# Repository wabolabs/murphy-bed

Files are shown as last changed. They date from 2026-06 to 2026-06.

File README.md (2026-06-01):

# Malm Queen → Murphy Bed Conversion

OSB cabinet + direct-bracket VEVOR kit conversion of an IKEA Malm Queen bed frame into a wall-mounted Murphy bed. Cost-optimized design: ~$260–330 in materials.

## Contents

| Path | Description |
|---|---|
| `design/design.html` | Full design doc with SVG diagrams, construction steps, shopping list |
| `design/design.md` | Same content in Markdown |
| `design/diagrams/` | 6 dimensioned SVG diagrams (assembly, panels, mounting, exploded, ceiling, bed-open) |
| `design/3d/` | Programmatic CadQuery 3D model (27-part assembly, STL/STEP, Three.js viewer) |
| `ref/` | Original VEVOR kit manual and IKEA MALM assembly instructions (PDFs) |

## 3D Viewer

```bash
./view.sh          # starts server + opens browser
# or manually:    python3 -m http.server 8080
# then open:      http://localhost:8080/design/3d/viewer.html
```

Opens a Three.js viewer with the full assembly in 3D. Orbit with mouse, switch between Open / Stored / Cabinet Only / Exploded views.

> Opening `design/3d/viewer.html` directly via `file://` will fail due to browser CORS policy. Use `./view.sh` to serve it locally.

## License

MIT — see [LICENSE](LICENSE).

The PDFs in `ref/` are copyright their respective owners (VEVOR/BAGUO and IKEA) and are included for reference only.

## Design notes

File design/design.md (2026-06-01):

# Malm Queen + VEVOR Murphy Bed Kit — Design Document (Cost-Optimized)

> **Project**: Convert an IKEA Malm Queen bed frame into a wall-mounted Murphy (fold-up) bed using a VEVOR/BAGUO Queen Vertical Murphy Bed Kit (YFHVQN246).  
> **Room constraint**: 83.5 in (2121 mm) ceiling with attic/crawl space above for recess.  
> **Date**: 2026-06-01 — **Updated for cost optimization**

---

## Contents

1. [Key Dimensions](#1-key-dimensions)
2. [Design Overview](#2-design-overview)
3. [Figure 1: Overall Assembly](#3-figure-1-overall-assembly)
4. [Figure 2: Cabinet Panel Cutting Guide](#4-figure-2-cabinet-panel-cutting-guide)
5. [Figure 3: Bracket Mounting Detail](#5-figure-3-bracket-mounting-detail)
6. [Figure 4: Exploded View](#6-figure-4-exploded-view)
7. [Figure 5: Ceiling Recess Framing Plan](#7-figure-5-ceiling-recess-framing-plan)
8. [Figure 6: Side View — Bed in Open Position](#8-figure-6-side-view--bed-in-open-position)
9. [Cost Optimization Summary](#9-cost-optimization-summary)
10. [Construction Steps](#10-construction-steps)
11. [Hardware Store Shopping List](#11-hardware-store-shopping-list)
12. [Assembly Sequence](#12-assembly-sequence)
13. [Key Constraints](#13-key-constraints)

---

## 1. Key Dimensions

### Room

| Measurement | US | Metric |
|---|---|---|
| Ceiling height | 83.5 in | 2121 mm |
| Above ceiling | Attic / crawl space | |

### VEVOR Murphy Bed Kit (Queen Vertical — YFHVQN246)

| Component | US | Metric |
|---|---|---|
| Cabinet internal (W × D × H) | 65 1/8 × 15 1/4 × 82 3/4 in | 1654 × 388 × 2102 mm |
| Cabinet external (w/ 3/4 in OSB) | **66.5 × 16 × 84.25 in** | **1690 × 406 × 2138 mm** |
| Kit bed frame (L × W) | 81 3/4 × 64 3/8 in | 2077 × 1634 mm |
| Queen mattress | 60 × 80 in | 1520 × 2030 mm |
| Max mattress weight | 68 lb | 31 kg |
| Total bed weight (frame + mattress) | 202-209 lb | 92-95 kg |

### IKEA Malm Bed Frame (Queen)

| Dimension | US | Metric |
|---|---|---|
| Overall length (with head/footboard) | 83 1/8 in (2111 mm) | |
| Overall width | 66 1/8 in (1680 mm) | |
| **Side rail length** (head/footboard **removed**) | **~79 1/2 in** | **~2020 mm** |
| Mattress platform width | 59 7/8 in | 1521 mm |
| Platform height off floor | 8 1/4 in | 210 mm |

### Ceiling Fit Analysis

| Component | US | Result |
|---|---|---|
| Cabinet external (3/4 in OSB) | **84.25 in (2138 mm)** | Fits with minimal recess |
| Ceiling height | 83.5 in (2121 mm) | |
| **Recess needed** | **0.65 in (17 mm)** | — no header required |
| Malm side rail (stored vertical) | ~79 1/2 in (~2020 mm) | Fits inside cabinet (82 3/4 in) |

---

## 2. Design Overview

**Approach**: Build the Murphy cabinet using **OSB (oriented strand board)** panels for cost savings, and mount the Murphy **Connect Brackets directly to the Malm side rails** — eliminating the plywood adapter strips. The cabinet is only slightly taller than the ceiling, requiring a **~5/8 in (17 mm) recess** — a simple trim-drywall detail rather than a structural framing project.

### Why This Works

1. **OSB is strong enough**: OSB has equivalent shear strength to plywood at the same thickness, and costs ~40% less. For a Murphy bed cabinet (static vertical load, well-braced), OSB is ideal.
2. **Direct mount is simpler**: The Connect Bracket's 11 mm pivot pin carries the full vertical load in shear. Drilling this hole directly into the Malm particleboard side rail is safe — the pin distributes the load, and the M5 screws just prevent rotation.
3. **Minimum ceiling recess**: With 3/4 in OSB panels (18 mm actual), the cabinet external height is 84.25 in. The ceiling is 83.5 in. The 0.65 in gap is easily handled with trim and blocking — no joist cutting or structural header needed.
4. **Lighter = better**: Eliminating the adapter strips (~5.5 lb) and M8 bolts (~1 lb) reduces total bed weight, helping the gas springs lift more easily.
5. **Reversible enough**: The only "permanent" modification is drilling 11 mm holes in the Malm side rails, which are hidden inside the cabinet. The bed can be returned to standalone use by filling the holes.

> **Cost savings summary**: OSB vs. plywood saves ~$75. No adapter strips saves ~$26 in hardware. No structural ceiling header saves ~$15. Total savings: **~$116** vs. the original design.

---

## 3. Figure 1: Overall Assembly

Overall Assembly

*Front elevation (left) and side section (right) showing the OSB cabinet with a 0.65 in ceiling recess.*

---

## 4. Figure 2: Cabinet Panel Cutting Guide

Panel Cutting Guide

*All cabinet panels cut from OSB. The back panel uses 1/2 in OSB for weight savings.*

### Panel Summary

| # | Description | US Dimensions | Metric | Material | Qty |
|---|---|---|---|---|---|
| 1 | Cabinet side | 84 1/4 × 16 in | 2138 × 406 mm | 3/4 in OSB | 2 |
| 2 | Cabinet top | 65 1/8 × 15 1/4 in | 1654 × 388 mm | 3/4 in OSB | 1 |
| 3 | Cabinet bottom | 65 1/8 × 16 in | 1654 × 406 mm | 3/4 in OSB | 1 |
| 4 | Interior shelf | 65 1/8 × 15 1/4 in | 1654 × 388 mm | 3/4 in OSB | 1 |
| 5 | Back panel | 82 3/4 × 66.5 in | 2102 × 1690 mm | 1/2 in OSB | 1 |

### Why OSB?

OSB (oriented strand board) is significantly cheaper than plywood:
- **3/4 in OSB (4×8)**: ~$35/sheet vs. ~$60 for sanded plywood
- **1/2 in OSB (4×8)**: ~$25/sheet vs. ~$55 for sanded plywood
- **Total savings**: ~$90-100 on sheet goods

OSB is strong in shear and compression — ideal for a cabinet box. The surface is rough, but since the cabinet is mostly hidden behind the bed, this isn't a concern. For visible areas, prime with shellac-based primer and paint, or face with 1/4 in plywood skin.

### Mattress Support

Instead of the kit's 3/8 in plywood mattress support panel, re-use the **existing Malm slatted base** (Luroy slats + SKORVA center beam). This is already included with the bed and provides excellent ventilation for the mattress.

---

## 5. Figure 3: Bracket Mounting Detail

Bracket Mounting

*Detail A: Side Bracket (A) mounted to 3/4 in OSB cabinet side. Detail B: Connect Bracket (B) mounted directly to the Malm particleboard side rail.*

### Direct-Mount Specifications

| Property | Value |
|---|---|
| Connect Bracket (B) mounting | Directly to Malm side rail via 11 mm pivot pin |
| Pivot hole in Malm rail | 7/16 in (11 mm) diameter — drill through particleboard |
| Screws for Bracket B | M5×20 mm (#10) — pre-drill pilot holes |
| Side Bracket (A) mounting | To OSB cabinet side with template 28 × 11 5/8 in (710 × 294 mm) |
| Side Bracket pivot hole depth | 5/8 in (15 mm) — leaves ~3 mm in 18 mm OSB |
| No adapter strips needed | Eliminates ~5.5 lb weight and ~$26 in hardware |

### Hole Pattern Transfer

Use the Connect Bracket drilling template (306 × 82 mm / 12 × 3 1/4 in) to mark the pivot pin and screw positions on the Malm side rail. Align the template so the bracket positions the bed at the correct height for the pivot geometry (see Figure 5).

### Particleboard Notes

Particleboard holds screws adequately when pilot holes are pre-drilled. The 11 mm pivot pin carries the vertical/shear load; the M5 screws only prevent the bracket from rotating. For extra grip, dip screws in wood glue before driving.

---

## 6. Figure 4: Exploded View

Exploded View

*All components shown in their relative positions: OSB cabinet panels, mechanism brackets, Malm side rails with slatted base.*

---

## 7. Figure 5: Ceiling Recess Framing Plan

Ceiling Framing

*Top view of ceiling rough opening and section of cabinet-ceiling interface.*

### Rough Opening Dimensions

| Dimension | US | Metric | Calculation |
|---|---|---|---|
| Width | **67.5 in** | **1715 mm** | Cabinet 66.5 in + ~1 in shim gap |
| Depth | **18 in** | **457 mm** | Cabinet 16 in + ~2 in for trim/access |

The recess is only **0.65 in (17 mm)** deep — this is purely a drywall/trim detail:

- Open ceiling drywall to expose joists in the opening area
- Install 2×4 blocking between joists for trim attachment
- No need to cut joists or install a header
- Shim cabinet plumb, fasten through sides into blocking with 3 in deck screws
- Install crown moulding or L-trim to conceal the gap

> **The 0.65 in recess requires no structural ceiling modifications.** This eliminates ~$15 in framing lumber and significant labor vs. the original 3.6 in recess design.

---

## 8. Figure 6: Side View — Bed in Open Position

Bed Open

*Side view of the bed in the horizontal (open) position with pivot geometry and gas spring.*

### Pivot Point Geometry

| Measurement | Value |
|---|---|
| Pivot center (Side Bracket A) | Matches kit template position |
| Leg C center-to-ground | **12 1/4 in (310 mm)** — per kit spec |
| Bed platform height off floor | ~12 1/4 in (Malm is 8 1/4 in — legs raise to match) |

---

## 9. Cost Optimization Summary

### What Changed vs. Original Design

| Item | Original | Optimized | Savings |
|---|---|---|---|
| Cabinet panels | Sanded plywood (3/4 in + 1/2 in) — ~$280 | OSB (3/4 in + 1/2 in) — ~$130 | **~$150** |
| Adapter strips | 2 × 3/4 in plywood strips | Eliminated — direct mount | **~$26** (hardware) |
| Ceiling header | Double 2×6 + cripples + drywall patch | Blocking only + trim | **~$15** |
| Total material cost | ~$420-500 | **~$260-330** | **~$130-170** |
| Weight (adapter + bolts) | ~6.5 lb added | 0 lb added | Bed is lighter |

### What's the Same

- Internal cabinet dimensions (1654 × 388 × 2102 mm)
- Bracket positions and templates
- Gas spring installation
- Malm bed frame with slatted base
- L-bracket hanger strips (3174 mm) for wall/cabinet attachment

### What Changed

- Cabinet panels: 3/4 in OSB instead of 3/4 in + 1 in plywood
- External dimensions: 1690 × 406 × 2138 mm (was 1704 × 438 × 2212 mm) — narrower, shorter
- Ceiling recess: 0.65 in (was 3.6 in)
- Mounting: Connect Bracket direct to Malm (no adapter strips)
- No 3/8 in mattress support panel needed — re-use Malm slats
- Fewer interior shelves: 1 shelf instead of 2

---

## 10. Construction Steps

### Phase 1: Ceiling Preparation

1. Locate ceiling joists with stud finder, mark opening: ~67.5 × 18 in
2. Cut drywall, install 2×4 blocking between joists at opening perimeter
3. Confirm rough opening is square and level

### Phase 2: Cabinet Construction

1. Cut all OSB panels per Figure 2
2. Assemble cabinet box with 3 in deck screws + waterproof wood glue (Titebond III)
3. Verify internal dimensions: **65 1/8 × 15 1/4 × 82 3/4 in**
4. Install interior shelf
5. Prime/paint visible surfaces with shellac-based primer (Zinsser BIN)

### Phase 3: Bracket Installation

1. Mount **Side Brackets (A)** to OSB cabinet interior using template **28 × 11 5/8 in (710 × 294 mm)**
2. Drill 7/16 in (11 mm) pivot hole 5/8 in (15 mm) deep + 1/4 in locator hole
3. Fix brackets with screws I (M5×20 mm) from kit

### Phase 4: Direct Mount Connect Brackets to Malm

1. Remove Malm headboard and footboard
2. Clamp Connect Bracket template **12 × 3 1/4 in (306 × 82 mm)** to each Malm side rail
3. Transfer hole positions (1 pivot + screw holes)
4. Pre-drill pilot holes for screws (3/16 in / 4.5 mm bit)
5. Drill 7/16 in (11 mm) pivot hole through particleboard
6. Mount **Connect Brackets (B)** with screws I — dip screws in wood glue for grip
7. Press **Bearings (F)** into Connect Brackets
8. Attach **Legs (C)** near foot end — 12 1/4 in center-to-ground
9. Install **Gas Springs (D)** — turn end caps out, thread into Connect Brackets, secure with M8 nuts

### Phase 5: Bed Frame Preparation

1. Reattach Malm slatted base (Luroy slats) to side rails
2. Install SKORVA center support beam
3. Slide bed frame assembly into cabinet — Connect Brackets ride on Side Brackets
4. Close and test pivot motion

### Phase 6: Final Assembly

1. Attach **Mattress Straps (E)** with Screws J — centered on mattress location
2. Install **Stoppers (G)** with Screws J
3. Slide cabinet into ceiling opening
4. Shim plumb, fasten through sides into ceiling blocking with 3 in deck screws every 12 in
5. Install crown moulding or L-trim around ceiling perimeter
6. Place mattress (max 10 in thick, max 68 lb) and secure with straps
7. Test open/close cycle multiple times — adjust gas spring tension as needed

---

## 11. Hardware Store Shopping List

### Sheet Goods (OSB)

| Item | Qty | Size | Purpose | Est. Cost |
|---|---|---|---|---|
| **3/4 in OSB (4 × 8 ft)** | 2 sheets | 4×8 ft × 23/32 in actual | Cabinet sides (2), top, bottom, shelf | ~$70 |
| **1/2 in OSB (4 × 8 ft)** | 1 sheet | 4×8 ft × 15/32 in actual | Back panel | ~$25 |
| **Total sheet goods** | | | | **~$95** |

### Lumber & Trim

| Item | Qty | Size | Purpose | Est. Cost |
|---|---|---|---|---|
| **2×4 SPF stud** | 2 | 92 5/8 in (standard stud) | Ceiling blocking | ~$8 |
| **Crown moulding or L-trim** | 14 ft | ~2-3 in profile | Ceiling transition trim | ~$20 |

### Fasteners & Hardware

| Item | Qty | Size | Purpose | Est. Cost |
|---|---|---|---|---|
| **Deck screws** | 1 box (1 lb) | #8 × 3 in | Cabinet assembly + cabinet to ceiling | ~$10 |
| **Deck screws** | 1/2 box | #8 × 1 1/4 in | Cabinet shelves | ~$5 |
| **Wood glue** | 1 bottle | Waterproof (Titebond III) | Cabinet assembly + screw grip | ~$8 |
| **Drywall screws** | 1/2 lb | #6 × 1 5/8 in | Ceiling drywall replacement | ~$5 |
| **Shims** | 1 pack | 12 in cedar | Level cabinet in ceiling opening | ~$5 |

### Finishing Supplies

| Item | Qty | Purpose | Est. Cost |
|---|---|---|---|
| **Shellac-based primer** (Zinsser BIN) | 1 qt | Prime OSB visible surfaces | ~$15 |
| **Paint** | 1 qt | Match room color | ~$10 |

### Tools (if not already owned)

| Item | Est. Cost | Notes |
|---|---|---|
| Circular saw or track saw | ~$80-150 | For OSB panel cutting |
| Jigsaw | ~$40-60 | Notch cuts for brackets |
| Power drill + bits | ~$60-120 | 7/16 in (11 mm) wood bit needed |
| #10 (M5) countersink bit | ~$10 | For bracket screws |
| Stud finder | ~$20 | Locate ceiling joists |
| Level (4 ft) | ~$25 | Cabinet alignment |
| Clamps (2 × 36 in) | ~$30 | Hold template during drilling |

### From the VEVOR Kit (included)

| Item | Qty |
|---|---|
| Side Bracket (A) | 2 |
| Connect Bracket (B) | 2 |
| Leg (C) | 2 |
| Gas Spring (D) — YFGS5001100 | 2 |
| Mattress Strap (E) | 2 |
| Bearing (F) | 4 |
| Stopper (G) | 2 |
| M8 nuts (H) | 4 |
| M5 × 20 mm screws (I) | 72 |
| M4 × 20 mm screws (J) | 8 |
| Drilling template (710 × 294 mm) | 1 |
| Drilling template (306 × 82 mm) | 1 |
| 13 mm open-end wrench | 1 |
| 6 mm wood drill bit | 1 |
| 11 mm wood drill bit | 1 |

### Estimated Total (hardware store portion): **~$260-330**

---

## 12. Assembly Sequence (Quick Reference)

```
 1. Cut ceiling drywall, install 2×4 blocking (~67.5 × 18 in opening)
 2. Cut + assemble OSB cabinet panels
 3. Mount Side Brackets (A) using template
 4. Mount Connect Brackets (B) directly to Malm side rails
 5. Press Bearings (F), attach Legs (C), install Gas Springs (D)
 6. Reattach Malm slatted base + SKORVA beam
 7. Slide bed frame into cabinet, test pivot
 8. Shim + fasten cabinet in ceiling opening
 9. Install crown moulding
10. Place mattress + straps + final test
```

---

## 13. Key Constraints

| Constraint | Limit | Why |
|---|---|---|
| **Mattress max weight** | 68 lb (31 kg) | Gas spring lift capacity |
| **Mattress max thickness** | 10 in (254 mm) | Cabinet depth when folded |
| **Mattress size** | Queen only — 60 × 80 in | Frame width + mechanism design |
| **Total bed weight** | ~205 lb (93 kg) | Gas spring pre-charge spec |
| **Ceiling recess** | ~5/8 in (17 mm) | Cabinet height minus ceiling height |

### Mattress Weight Guidelines

The gas springs are calibrated for a total bed weight (frame + mattress) of **202-209 lb (92-95 kg)**. The Malm frame, slatted base, and hardware weigh approximately **60-70 lb (27-32 kg)**. The lighter OSB cabinet saves ~5-8 lb vs. plywood. This leaves roughly **130-145 lb (59-66 kg)** for the mattress — but the kit explicitly states **max mattress weight: 68 lb (31 kg)**.

Verify your mattress weight before purchase. Most standard queen mattresses under 10 in thickness weigh **40-60 lb**. If you exceed the weight limit, the gas springs won't lift properly. Heavier mattresses require higher-force gas springs (available from VEVOR or aftermarket).

> **Tip:** Ask at the mattress store for a "lightweight queen" or look for mattresses with the lowest coil count. Latex and thin memory foam mattresses tend to be lightest.

---

## 14. 3D Model

A programmatic 3D model of the full assembly is available in `design/3d/`. It was generated using CadQuery (Python CAD library) and includes two configurations:

### Open Position
Bed frame extended horizontally from the cabinet front at bed height (310 mm / 12.25 in). Shows the cabinet recessed into the ceiling, room context (floor, wall, ceiling with cutout), OSB panels with OSB wood color, Malm bed frame, mattress, simplified brackets, gas springs, and legs touching the floor.

### Stored Position
Bed frame rotated vertically inside the cabinet. Same components, different configuration. The bed fits within the cabinet internal space with comfortable clearance.

### Viewing

| File | Description |
|---|---|
| `design/3d/viewer.html` | Three.js web viewer — open in a browser, mouse-drag to orbit |
| `design/3d/murphy_bed_3d.py` | CadQuery Python script — regenerate with `python3 murphy_bed_3d.py` |
| `design/3d/stl/*.stl` | Individual component STL files (27 parts per configuration) |
| `design/3d/step/*.step` | Individual component STEP files (CAD-compatible) |
| `design/3d/manifest.json` | Part manifest with colors and groups used by the viewer |

### Views in the 3D Viewer
- **Open** — assembled in open (horizontal) position
- **Stored** — assembled in stored (vertical) position
- **Cabinet Only** — just the OSB cabinet panels
- **Exploded** — components separated by group (room → cabinet → bed → mechanism)

### Regenerating
```bash
cd design/3d
python3 murphy_bed_3d.py      # exports both STL and STEP
python3 murphy_bed_3d.py stl  # STL only
python3 murphy_bed_3d.py step  # STEP only
```

---

## File Index

```
murphy-bed/
├── README.md                  ← Repo overview
├── view.sh                    ← Start 3D viewer (local HTTP server)
├── LICENSE                    ← MIT
├── ref/                       ← Original PDFs (VEVOR kit manual, IKEA MALM instructions)
│   ├── (BAGUO)SKU6-MurphyBedKit-...
│   └── malm-bed-frame-black-brown__AA-740446-8-2.pdf
└── design/
    ├── design.md              ← This document
    ├── design.html            ← HTML version for browser viewing
    ├── diagrams/
    │   ├── assembly.svg       Figure 1 — Overall assembly
    │   ├── panels.svg         Figure 2 — Panel cutting guide
    │   ├── mounting.svg       Figure 3 — Bracket mounting detail
    │   ├── exploded.svg       Figure 4 — Exploded view
    │   ├── ceiling.svg        Figure 5 — Ceiling recess framing
    │   └── bed-open.svg       Figure 6 — Bed in open position
    └── 3d/
        ├── murphy_bed_3d.py   CadQuery Python script
        ├── viewer.html        Three.js web viewer
        ├── manifest.json      Part manifest
        ├── stl/               Individual STL files (27 per configuration)
        └── step/              Individual STEP files
```

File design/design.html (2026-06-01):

# Malm Queen + VEVOR Murphy Bed Kit

Cost-Optimized Design — OSB Cabinet + Direct Mount

Model YFHVQN246 • Queen Vertical • Room Ceiling 83.5 in • June 2026

~$260-330 materials — saves ~$170 vs. plywood original

## 1. Key Dimensions

### Room

Measurement | US | Metric
Ceiling height | 83.5 in | 2121 mm
Above ceiling | Attic / crawl space

### VEVOR Murphy Bed Kit (Queen Vertical — YFHVQN246)

Component | US | Metric
Cabinet internal (W × D × H) | 65 1/8 × 15 1/4 × 82 3/4 in | 1654 × 388 × 2102 mm
Cabinet external (3/4 in OSB) | 66.5 × 16 × 84.25 in | 1690 × 406 × 2138 mm
Kit bed frame (L × W) | 81 3/4 × 64 3/8 in | 2077 × 1634 mm
Queen mattress | 60 × 80 in | 1520 × 2030 mm
Max mattress weight | 68 lb | 31 kg
Total bed weight (frame + mattress) | 202-209 lb | 92-95 kg

### IKEA Malm Bed Frame (Queen)

Dimension | US | Metric
Overall length (with head/footboard) | 83 1/8 in | 2111 mm
Overall width | 66 1/8 in | 1680 mm
Side rail (head/foot removed) | ~79 1/2 in | ~2020 mm
Mattress platform width | 59 7/8 in | 1521 mm
Platform height off floor | 8 1/4 in | 210 mm

### Ceiling Fit Analysis

Component | Height | Result
Cabinet external (3/4 in OSB) | 84.25 in (2138 mm) | Fits with minimal recess
Ceiling height | 83.5 in (2121 mm)
Recess needed | 0.65 in (17 mm) | No header required!
Malm side rail (stored vertical) | ~79 1/2 in (~2020 mm) | Fits inside cabinet (82 3/4 in)

## 2. Design Overview

Approach: Build the Murphy cabinet using OSB (oriented strand board) panels for cost savings, and mount the Murphy Connect Brackets directly to the Malm side rails — eliminating the plywood adapter strips. The cabinet is only slightly taller than the ceiling, requiring a ~5/8 in (17 mm) recess — a simple trim detail rather than a structural framing project.

Bottom line: This design saves ~$170 vs. the original plan by using OSB instead of plywood, eliminating adapter strips and their hardware, and removing the need for a structural ceiling header. The bed is also lighter (better for gas springs) and simpler to build.

### Why OSB?

- Cost: 3/4 in OSB is ~$35/sheet vs. ~$60 for sanded plywood — saves ~$90-100 on sheet goods
- Strength: OSB has equivalent shear and compression strength to plywood at the same thickness
- Appearance: The cabinet interior is mostly hidden behind the bed. Visible faces can be primed with shellac-based primer (Zinsser BIN) and painted

### Why Direct Mount (No Adapters)?

- Weight: Eliminates ~5.5 lb (2.5 kg) of plywood strips and ~1 lb (0.5 kg) of bolts
- Cost: Saves ~$26 in M8 bolts, washers, nylock nuts
- Simplicity: Fewer parts, fewer holes to drill, fewer things to go wrong
- Safety: The 11 mm pivot pin carries the full vertical load in shear — particleboard handles this fine with pre-drilled pilot holes

One trade-off: Drilling 11 mm holes in the Malm side rails is technically permanent. However, the holes are hidden inside the cabinet, and the bed can be returned to standalone use by filling them with wood filler + touch-up paint. The adapter strip approach remains available if you prefer full reversibility.

## 3. Figure 1: Overall Assembly

Overall assembly

Front elevation (left) and side section (right) — OSB cabinet with 0.65 in ceiling recess.

## 4. Figure 2: Cabinet Panel Cutting Guide

Panel cutting guide

All panels cut from OSB. 3/4 in for structure, 1/2 in for back panel. Savings: ~$100 vs. plywood.

### Panel Summary

# | Description | US Dimensions | Metric | Material | Qty

1 | Cabinet side | 84 1/4 × 16 in | 2138 × 406 mm | 3/4 in OSB | 2
2 | Cabinet top | 65 1/8 × 15 1/4 in | 1654 × 388 mm | 3/4 in OSB | 1
3 | Cabinet bottom | 65 1/8 × 16 in | 1654 × 406 mm | 3/4 in OSB | 1
4 | Interior shelf | 65 1/8 × 15 1/4 in | 1654 × 388 mm | 3/4 in OSB | 1
5 | Back panel | 82 3/4 × 66.5 in | 2102 × 1690 mm | 1/2 in OSB | 1

### Mattress Support

Re-use the existing Malm slatted base (Luroy slats + SKORVA center beam) instead of cutting a 3/8 in plywood panel. The slats provide better mattress ventilation and are already the correct size.

## 5. Figure 3: Bracket Mounting Detail

Bracket mounting detail

Side Bracket (A) on OSB cabinet / Connect Bracket (B) direct to Malm side rail — no adapter strips.

### Mechanism Components

Part | Description | Fasteners
A — Side Bracket | Mounts to cabinet side (OSB) | Template 28 × 11 5/8 in (710×294 mm), screws I
B — Connect Bracket | Mounts directly to Malm side rail | Template 12 × 3 1/4 in (306×82 mm), screws I
C — Leg | Supports bed when horizontal | 7/16 in pin + screws I
D — Gas Spring | Lifting assist | M8 threaded, Nut H
E — Mattress Strap | Secures mattress | Screw J (M4×20)
F — Bearing | Rides in Side Bracket track | Press-fit into B
G — Stopper | Limits bed travel | Screw J

## 6. Figure 4: Exploded View

Exploded view

OSB cabinet, mechanism brackets, Malm side rails with slatted base — no adapter strips.

## 7. Figure 5: Ceiling Recess Framing Plan

Ceiling framing

Rough opening: 67.5 × 18 in (1715 × 457 mm). Recess is only 0.65 in — no header needed!

No structural ceiling work required. The 0.65 in (17 mm) recess is purely a drywall/trim detail: cut drywall, add 2×4 blocking between joists for trim attachment, shim cabinet plumb, fasten through sides. No joist cutting, no header, no cripple studs.

## 8. Figure 6: Side View — Bed in Open Position

Bed open

Bed horizontal: pivot point, gas spring, legs at 12 1/4 in ground clearance.

## 9. Cost Optimization Summary

Item | Original (Plywood + Adapter) | Optimized (OSB + Direct Mount) | Savings
Cabinet panels | 3/4 in sanded plywood (3 sheets) + 1/2 in plywood (1 sheet) + 3/8 in plywood (1 sheet) | 3/4 in OSB (2 sheets) + 1/2 in OSB (1 sheet) | ~$100
Ceiling header+framing | 12 ft 2×6 + 40 ft 2×4 + drywall patch | 2 × 2×4 blocking + trim | ~$37
Adapter hardware | 20 M8 bolts + 40 washers + 20 nylock nuts | None (direct mount) | ~$26
Weight (adapter + bolts) | ~6.5 lb added to bed | 0 lb added | Bed is lighter
Ceiling recess | 3.6 in (91 mm) — structural | 0.65 in (17 mm) — trim only | Much easier
Total material cost | ~$420-500 | ~$260-330 | ~$130-170 saved

## 10. Construction Steps

### Phase 1: Ceiling Preparation

1. Locate ceiling joists with stud finder, mark opening: ~67.5 × 18 in
2. Cut drywall, install 2×4 blocking between joists at opening perimeter
3. Confirm rough opening is square and level

### Phase 2: Cabinet Construction

1. Cut all OSB panels per Figure 2
2. Assemble cabinet box with 3 in deck screws + waterproof wood glue (Titebond III)
3. Verify internal: 65 1/8 × 15 1/4 × 82 3/4 in
4. Install interior shelf
5. Prime/paint visible surfaces with shellac-based primer (Zinsser BIN)

### Phase 3: Side Bracket Installation

1. Mount Side Brackets (A) using template 28 × 11 5/8 in (710×294 mm)
2. Drill 7/16 in (11 mm) pivot hole 5/8 in (15 mm) deep + 1/4 in locator hole
3. Fix brackets with screws I (M5×20 mm) from kit

### Phase 4: Direct Mount Connect Brackets to Malm

1. Remove Malm headboard and footboard
2. Clamp Connect Bracket template 12 × 3 1/4 in (306×82 mm) to each Malm side rail
3. Transfer hole positions (1 pivot + screw holes)
4. Pre-drill pilot holes for screws (3/16 in / 4.5 mm bit)
5. Drill 7/16 in (11 mm) pivot hole through particleboard
6. Mount Connect Brackets (B) with screws I — dip screws in wood glue for grip
7. Press Bearings (F) into Connect Brackets
8. Attach Legs (C) near foot end — 12 1/4 in center-to-ground
9. Install Gas Springs (D) — turn end caps out, thread into Connect Brackets, secure with M8 nuts

### Phase 5: Bed Frame Preparation

1. Reattach Malm slatted base (Luroy slats) to side rails
2. Install SKORVA center support beam
3. Slide bed frame assembly into cabinet — Connect Brackets ride on Side Brackets
4. Close and test pivot motion

### Phase 6: Final Assembly

1. Attach Straps (E) with Screws J
2. Install Stoppers (G)
3. Slide cabinet into ceiling opening
4. Shim plumb, fasten through sides into ceiling blocking with 3 in deck screws every 12 in
5. Install crown moulding or L-trim around ceiling perimeter
6. Place mattress (max 10 in, max 68 lb) and secure with straps
7. Test open/close cycle multiple times — adjust gas spring tension as needed

## 11. Hardware Store Shopping List

### Sheet Goods (OSB)

Item | Qty | Size | Purpose | Est. Cost
3/4 in OSB (4 × 8 ft) | 2 sheets | 48 × 96 × 23/32 in | Cabinet sides, top, bottom, shelf | ~$70
1/2 in OSB (4 × 8 ft) | 1 sheet | 48 × 96 × 15/32 in | Back panel | ~$25
Plywood equivalent | 5 sheets | Would cost ~$280 — you save ~$185 | | ~$95

### Lumber & Trim

Item | Qty | Size | Purpose | Est. Cost
2×4 SPF stud | 2 | 92 5/8 in (standard stud) | Ceiling blocking | ~$8
Crown moulding or L-trim | 14 ft | ~2-3 in profile | Ceiling transition trim | ~$20

### Fasteners & Hardware

Item | Qty | Size | Purpose | Est. Cost
Deck screws | 1 lb | #8 × 3 in | Cabinet assembly + cabinet-to-ceiling | ~$10
Deck screws | 1/2 lb | #8 × 1 1/4 in | Shelf installation | ~$5
Waterproof wood glue | 1 bottle | Titebond III | Cabinet assembly + screw grip | ~$8
Drywall screws | 1/2 lb | #6 × 1 5/8 in | Ceiling drywall replacement | ~$5
Shims | 1 pack | 12 in cedar | Level cabinet in ceiling | ~$5

### Finishing Supplies

Item | Qty | Purpose | Est. Cost
Shellac-based primer (Zinsser BIN) | 1 qt | Prime OSB visible surfaces | ~$15
Paint (to match room) | 1 qt | Finish cabinet exterior | ~$10

### Tools (if not already owned)

Item | Est. Cost | Notes
Circular saw or track saw | ~$80-150 | For OSB panel cutting
Jigsaw | ~$40-60 | Notch cuts for brackets
Power drill + bits | ~$60-120 | 7/16 in (11 mm) wood bit needed
#10 (M5) countersink bit | ~$10 | For bracket screws

Stud finder | ~$20 | Locate ceiling joists
Level (4 ft) | ~$25 | Cabinet alignment
Clamps (2 × 36 in) | ~$30 | Hold template during drilling

### From the VEVOR Kit (included)

Item | Qty
Side Bracket (A) | 2
Connect Bracket (B) | 2
Leg (C) | 2
Gas Spring (D) — YFGS5001100 | 2
Mattress Strap (E) | 2
Bearing (F) | 4
Stopper (G) | 2
M8 nuts (H) | 4
M5 × 20 mm screws (I) | 72
M4 × 20 mm screws (J) | 8
Drilling templates | 2
13 mm wrench + 6 mm + 11 mm bits | 1 set

Estimated hardware store total (not including tools): ~$260-330

Savings: This is ~$170 less than the original plywood+adapter design. If you need to buy tools, add ~$260-415. Lowe's and Home Depot both carry all items listed. Prices checked June 2026.

## 12. Assembly Sequence (Quick Reference)

1. Cut ceiling drywall, install 2×4 blocking
2. Cut + assemble OSB cabinet
3. Mount Side Brackets (A) on cabinet
4. Mount Connect Brackets (B) directly to Malm rails
5. Press Bearings (F), attach Legs (C)
6. Install Gas Springs (D)
7. Reattach slatted base + SKORVA
8. Slide bed frame into cabinet
9. Test pivot motion
10. Shim + fasten cabinet in ceiling
11. Crown moulding
12. Mattress + straps + final test

## 13. Key Constraints

Constraint | Limit | Why
Mattress max weight | 68 lb (31 kg) | Gas spring lift capacity
Mattress max thickness | 10 in (254 mm) | Cabinet depth when folded
Mattress size | Queen — 60 × 80 in | Frame width + mechanism
Total bed weight | ~205 lb (93 kg) | Gas spring pre-charge
Ceiling recess | ~0.65 in (17 mm) | OSB cabinet minus ceiling height

Mattress weight warning: The gas springs are calibrated for a total bed weight of 202-209 lb (92-95 kg). The Malm frame + slatted base + hardware weighs approximately 60-70 lb (27-32 kg). The lighter OSB cabinet saves ~5-8 lb vs. plywood. This leaves roughly 130-145 lb (59-66 kg) for the mattress — but the kit explicitly states max mattress weight: 68 lb (31 kg). Check your mattress weight before buying. Most standard queen mattresses under 10 in weigh 40-60 lb. Ask for a "lightweight queen" or look for low-coil-count mattresses. If you exceed the limit, the gas springs won't lift properly.

## 14. 3D Model

A programmatic 3D model of the full assembly is available in design/3d/. It was generated using CadQuery (Python CAD library) and includes two configurations.

### Open Position

Bed frame extended horizontally from the cabinet front at bed height (310 mm / 12.25 in). Shows the cabinet recessed into the ceiling, room context (floor, wall, ceiling with cutout), OSB panels with wood color, Malm bed frame, mattress, simplified brackets, gas springs, and legs touching the floor.

### Stored Position

Bed frame rotated vertically inside the cabinet. The bed fits within the cabinet internal space with comfortable clearance (62 mm at foot, 20 mm at head).

### Viewing

File | Description
design/3d/viewer.html | Three.js web viewer — open in a browser, mouse-drag to orbit
design/3d/murphy_bed_3d.py | CadQuery Python script — regenerate with python3 murphy_bed_3d.py
design/3d/stl/*.stl | Individual component STL files (27 parts per configuration)
design/3d/step/*.step | Individual component STEP files (CAD-compatible)
design/3d/manifest.json | Part manifest with colors and groups for the viewer

### Views in the 3D Viewer

- Open — assembled in open (horizontal) position
- Stored — assembled in stored (vertical) position
- Cabinet Only — just the OSB cabinet panels
- Exploded — components separated by group (room → cabinet → bed → mechanism)

### Launching the Viewer

./view.sh          # from repo root — starts server + opens browser
# or manually:
python3 -m http.server 8080
# then open http://localhost:8080/design/3d/viewer.html

Note: Opening viewer.html directly via file:// will fail due to browser CORS policy. Always serve it over HTTP.

### Regenerating

cd design/3d
python3 murphy_bed_3d.py      # exports both STL and STEP
python3 murphy_bed_3d.py stl  # STL only
python3 murphy_bed_3d.py step # STEP only

## File Index

├── README.md ← Repo overview
├── view.sh ← Start 3D viewer
├── LICENSE ← MIT
├── .gitignore
├── ref/
├── (BAGUO)SKU6-MurphyBedKit-...
└── malm-bed-frame-black-brown__AA-740446-8-2.pdf
└── design/
├── design.html ← this file
├── design.md ← Markdown source
├── diagrams/ (6 SVG files)
└── 3d/
├── murphy_bed_3d.py
├── viewer.html
├── manifest.json
├── stl/ (27 files)
└── step/ (27 files)

Cost-optimized from VEVOR/BAGUO Murphy Bed Kit (YFHVQN246) + IKEA MALM Queen assembly instructions.
Verify all measurements against your physical components before cutting.

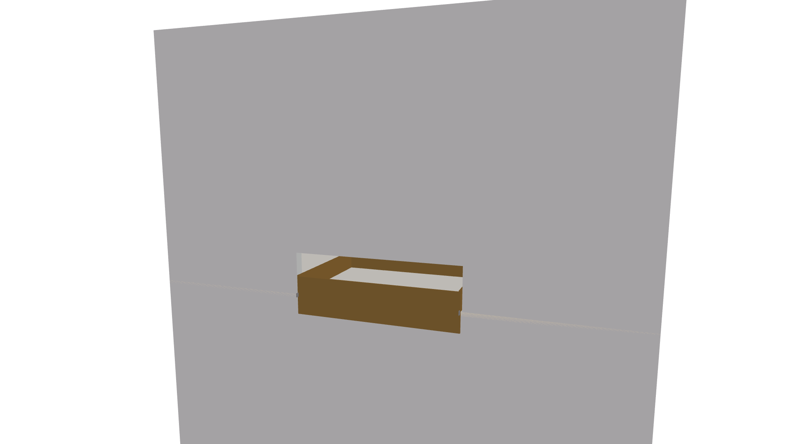
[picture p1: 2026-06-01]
design/3d/screenshots/open-low.png

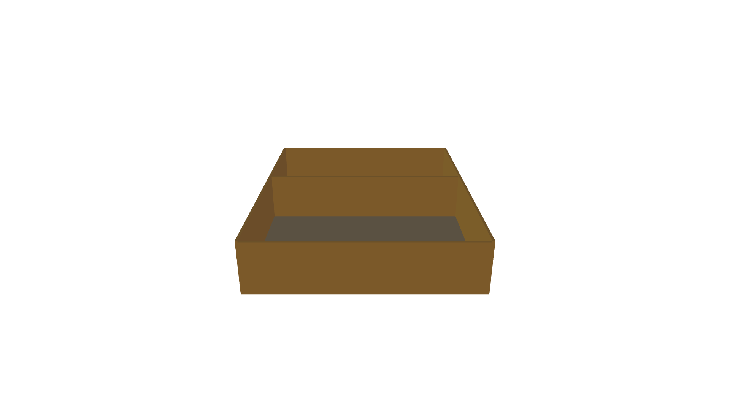
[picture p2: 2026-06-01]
design/3d/screenshots/cabinet-front.png

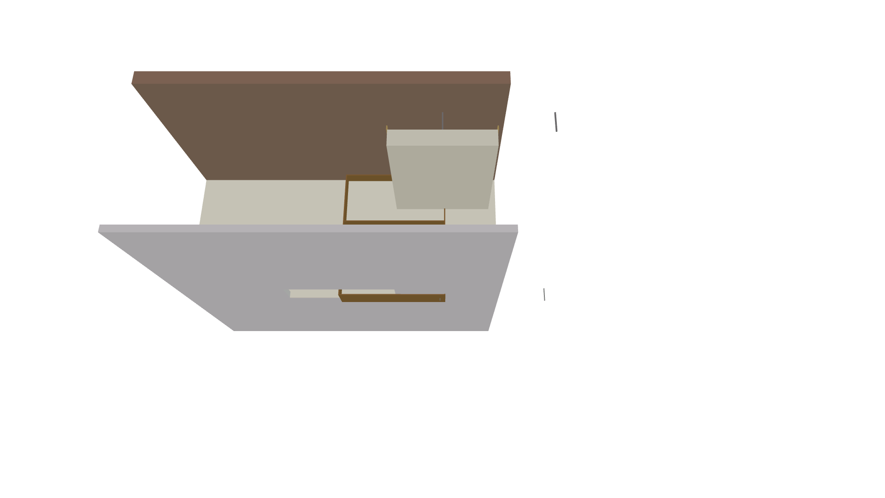
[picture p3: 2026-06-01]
design/3d/screenshots/exploded-topwide.png

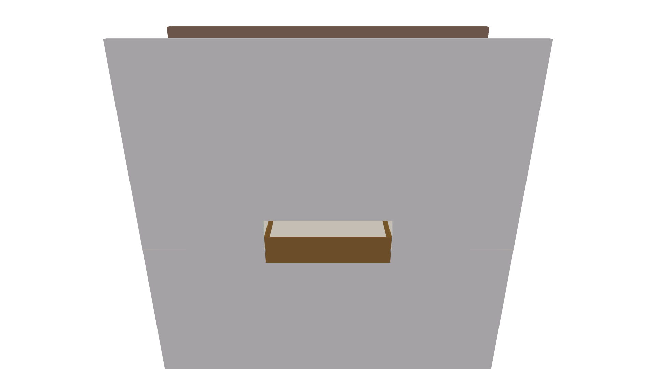
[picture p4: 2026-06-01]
design/3d/screenshots/open-front.png

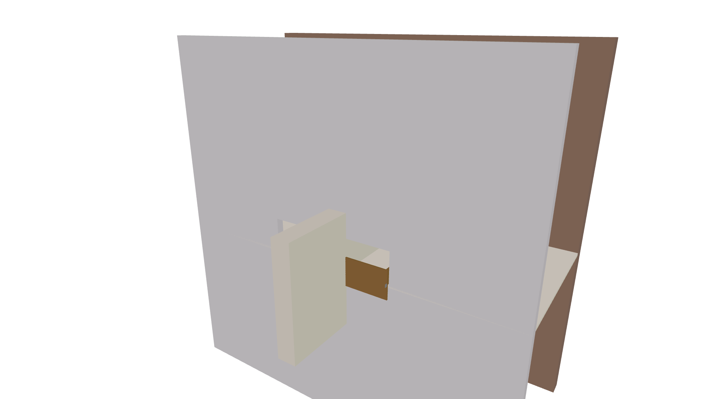
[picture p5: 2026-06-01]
design/3d/screenshots/stored-angle.png

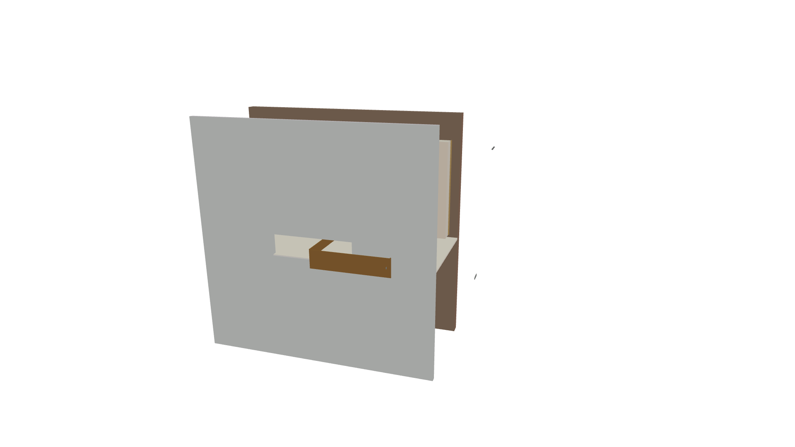
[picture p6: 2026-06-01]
design/3d/screenshots/exploded-overview.png

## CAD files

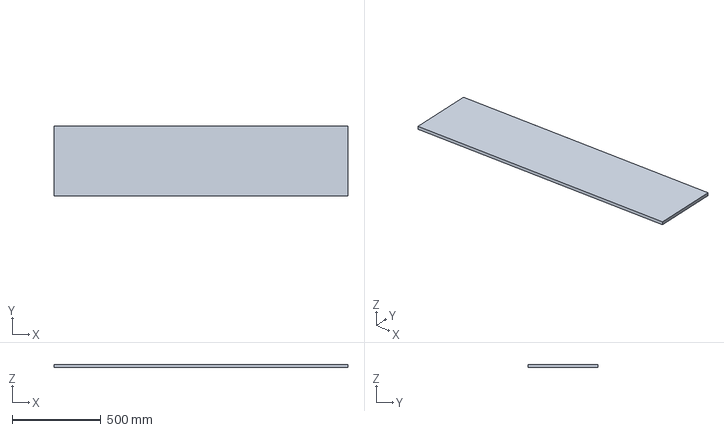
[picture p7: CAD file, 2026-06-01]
design/3d/step/stored_cab_shelf.step
1654.0 x 394.0 x 18.0 mm

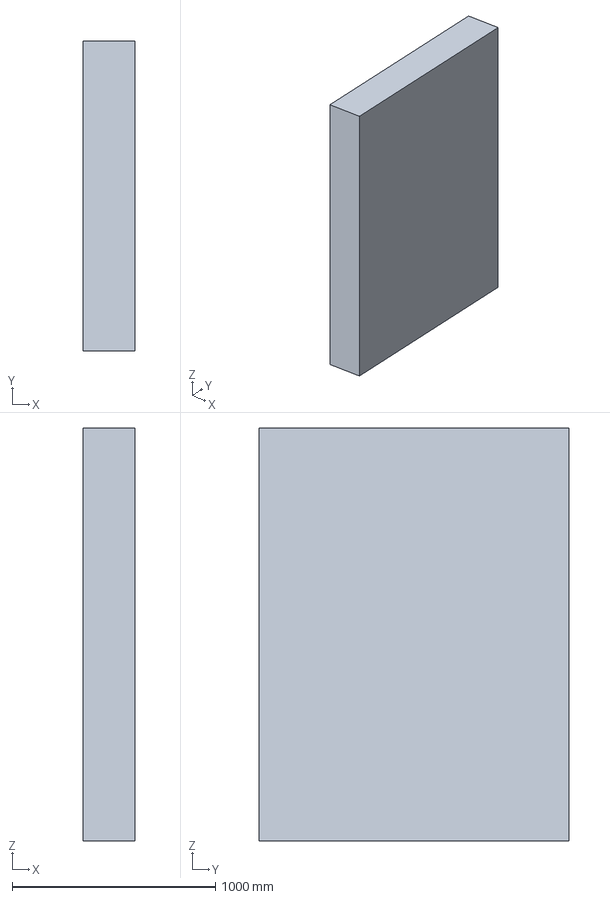
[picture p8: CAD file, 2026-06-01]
design/3d/step/stored_mattress.step
254.0 x 1525.0 x 2030.0 mm

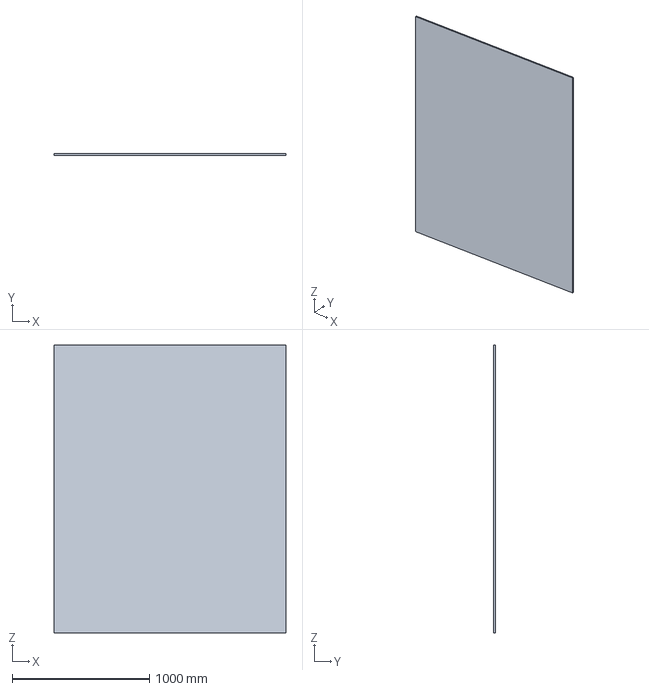
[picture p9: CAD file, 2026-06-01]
design/3d/step/open_cab_back.step
1690.0 x 12.0 x 2102.0 mm

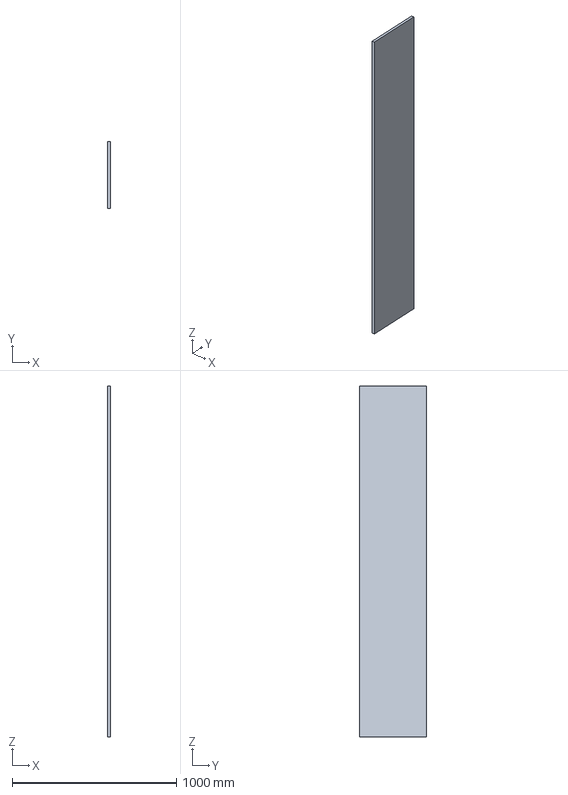
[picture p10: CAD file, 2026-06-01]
design/3d/step/stored_cab_side_L.step
18.0 x 406.0 x 2138.0 mm

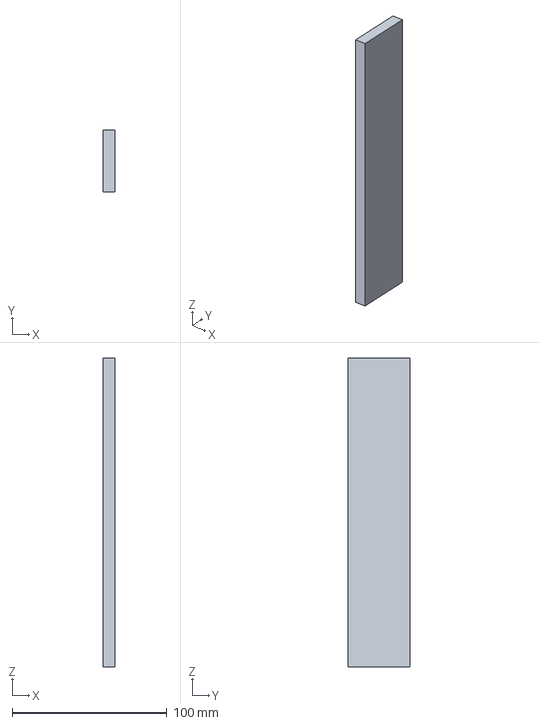
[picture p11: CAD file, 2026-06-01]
design/3d/step/stored_bracket_A_L.step
8.00 x 40.0 x 200.0 mm

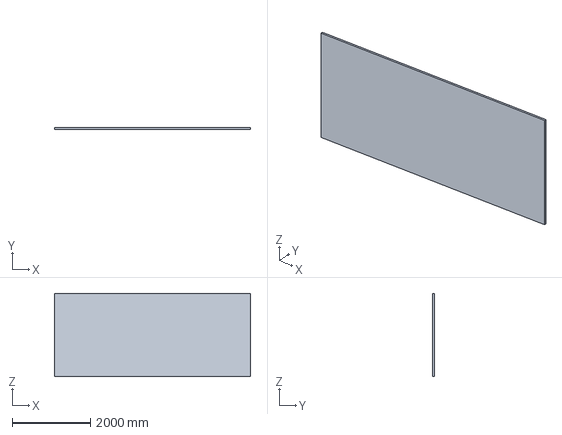
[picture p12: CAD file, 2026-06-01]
design/3d/step/open_wall.step
5000.0 x 40.0 x 2121.0 mm

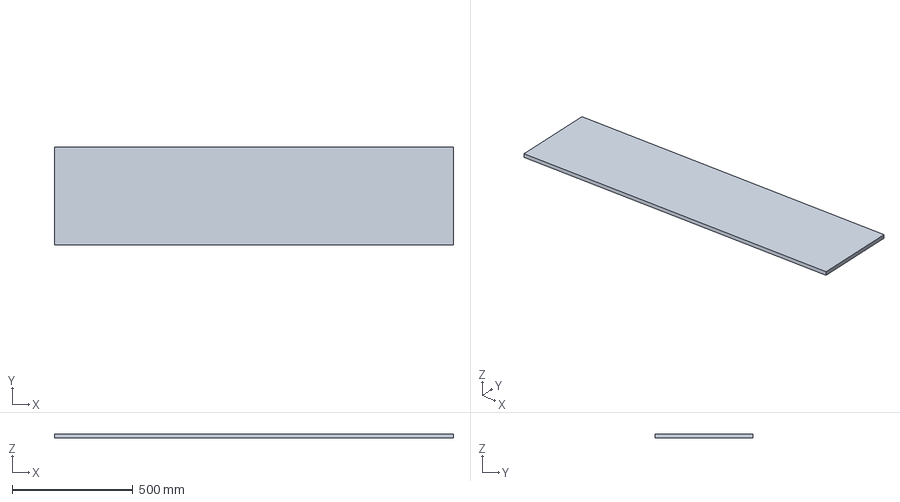
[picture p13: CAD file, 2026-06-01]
design/3d/step/open_cab_bottom.step
1654.0 x 406.0 x 18.0 mm

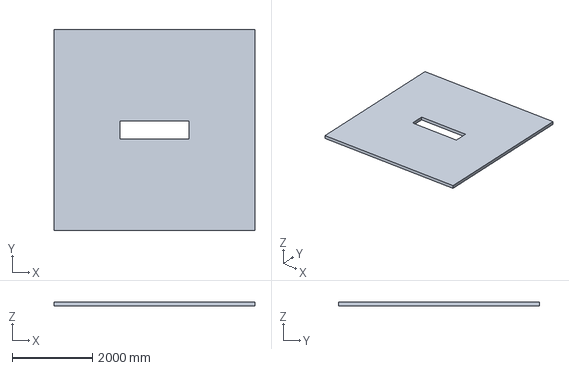
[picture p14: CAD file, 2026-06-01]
design/3d/step/open_ceiling.step
5000.0 x 5000.0 x 100.0 mm

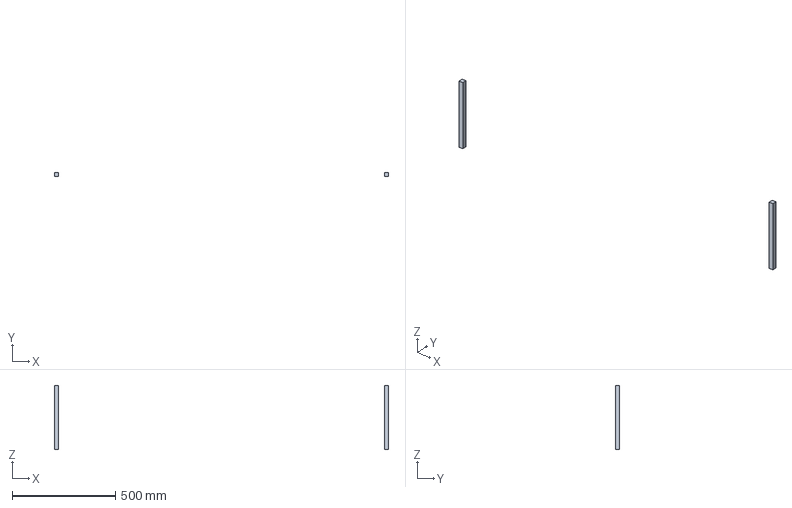
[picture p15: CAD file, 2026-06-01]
design/3d/step/open_legs.step
1617.0 x 20.0 x 310.0 mm

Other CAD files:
design/3d/step/open_cab_shelf.step
design/3d/step/open_cab_top.step
design/3d/step/open_cab_side_R.step
design/3d/step/stored_cab_side_R.step
design/3d/step/stored_bracket_A_R.step
design/3d/step/stored_cab_bottom.step
design/3d/step/stored_wall.step
design/3d/step/open_bracket_A_R.step
design/3d/step/stored_cab_back.step
design/3d/step/open_bed.step
design/3d/step/open_bracket_A_L.step
design/3d/step/open_cab_side_L.step
design/3d/step/open_floor.step
design/3d/step/open_mattress.step
design/3d/step/stored_bed.step
design/3d/step/stored_cab_top.step
design/3d/step/stored_ceiling.step
design/3d/step/stored_floor.step
design/3d/stl/open_bed.stl
design/3d/stl/open_bracket_A_L.stl
design/3d/stl/open_bracket_A_R.stl
design/3d/stl/open_cab_back.stl
design/3d/stl/open_cab_bottom.stl
design/3d/stl/open_cab_shelf.stl
design/3d/stl/open_cab_side_L.stl
design/3d/stl/open_cab_side_R.stl
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

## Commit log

2026-06-01 Initial design: Malm Queen + VEVOR Murphy bed conversion
    Cost-optimized design using OSB cabinet panels and direct bracket-to-Malm
    mounting (no adapter strips). Includes dimensioned SVGs, markdown, and
    HTML design document with hardware store shopping list (~60-330).
2026-06-01 Add programmatic 3D model (CadQuery) + viewer
    27-component 3D assembly of the Murphy bed in open and stored
    positions, generated with CadQuery. Includes STL/STEP exports,
    Three.js web viewer, and updated design docs with Section 14.
    [open_bed.step, open_bed.stl, open_bracket_A_L.step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]
2026-06-01 Add view.sh launcher; fix viewer CORS fallback
    - view.sh: starts python3 http.server on port 8080, opens viewer in browser
    - viewer.html: show clear error message when CORS blocks STL loading
    - README + design docs: update instructions to use ./view.sh
2026-06-01 Add 3D screenshots from multiple angles
    13 PNGs rendered via trimesh+pyglet (headless, no browser). Includes
    render_shots.py for regeneration. open/stored/cabinet/exploded views
    from front, angle, side, low, top, rear perspectives.
    Also expose camera controls on window.__setView for headless use.
